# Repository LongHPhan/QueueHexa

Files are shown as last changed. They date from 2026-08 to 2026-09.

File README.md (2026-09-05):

# QueueHexa

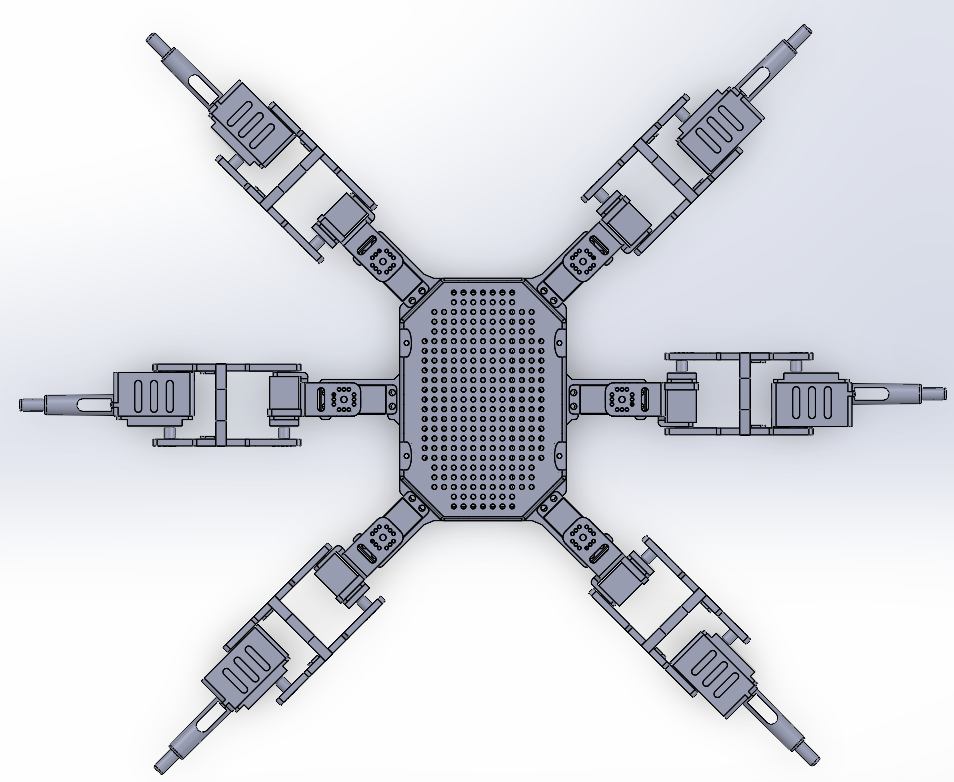
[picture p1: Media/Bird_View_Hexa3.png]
Hexapod Bird View


## Demo Video
  - [Hexapod Demo](https://youtu.be/oY_q5AbP_lc)

## Purpose
This is a personal robotics project created to hone my skills in CAD, electronics, and embedded programming. The idea is to design and build a six-legged hexapod robot from scratch: modeling, selecting the electronics, and programming custom inverse kinematics and gait control.

## Project Status
**In Development (Prototype Finished)**

Awaited improvements:
  - Add an accelerometer for motion/orientation feedback
  - Add leg position sensors
  - Integrate LiDAR for environmental sensing

## Hardware
  - Arduino Uno
  - PCA9685 servo driver(s)
  - MG996R servos
  - 35 kg high-torque servos
  - 7.4 V 5200 mAh battery
  - YPG 20A HV SBEC

## Development Journey
  Throughout the project, designing a reliable leg was one of the biggest challenges. The basic CAD process was simple; however, experimenting with the design in real life took multiple attempts before the leg was finally strong enough.
  
  For instance, the leg's joint went through two major changes: adding a peg and reinforcing the sides. These small details were overlooked in my initial design; however, their addition took the robot from crumbling under its own weight to being able to stand with only three of its legs.
  
  The hexapod's body also went through a similar process, however, with most changes aimed to minimize the usage of screws while considering space for electronics.
  
  The initial design was aimed to maximize modularity: the leg can be dissembled from the body plate was its own parts. However, the constant re-screwing made maintenance exhausting. With the 2nd prototypes, the layout changed from utilizing plates to a strong central frame, reducing the required screws to 4.

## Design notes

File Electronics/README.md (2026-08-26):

# Notice
One of the PCA address must be change to 0x41, to do so check out: https://learn.adafruit.com/16-channel-pwm-servo-driver/chaining-drivers.

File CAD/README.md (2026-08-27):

# Prototype
Both prototype 1 and 2 are fully functional with my current circuit and program. However, prototype 2 would provide a better experience as it is cleaner and uses significantly less screws. 

If you wished to use prototype 1, make sure your buck converter/UBEC/SBEC can provide a minimum of 15 amps.

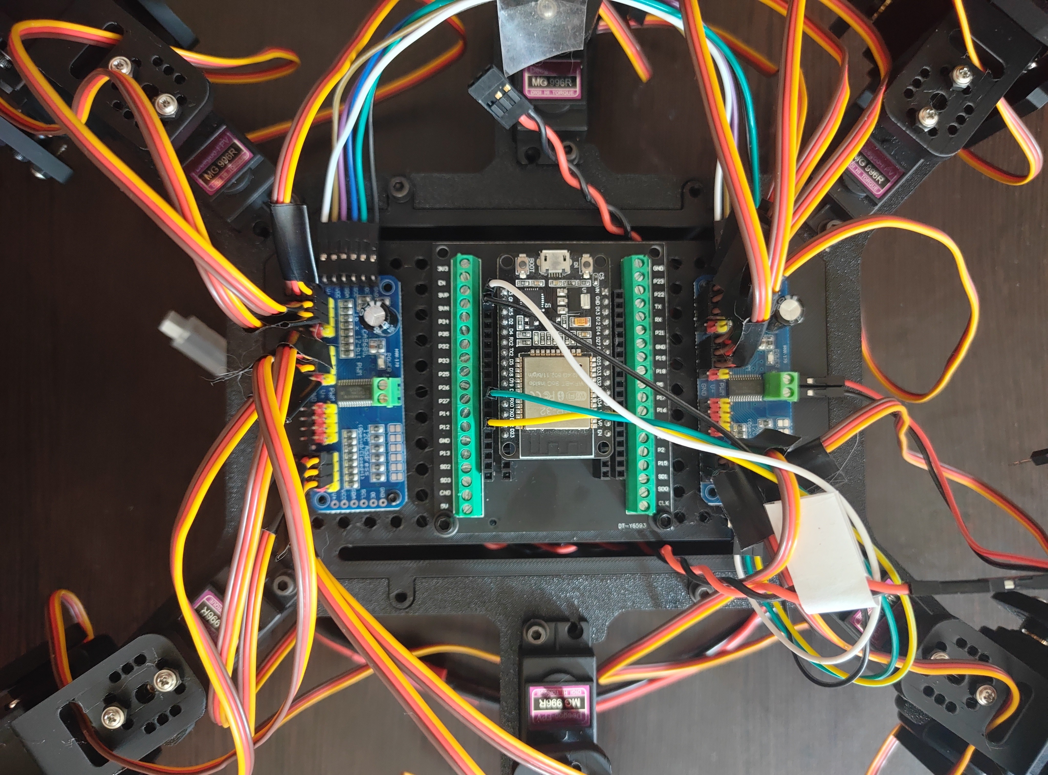
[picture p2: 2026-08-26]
Media/Protoype 2_Electronics.jpg

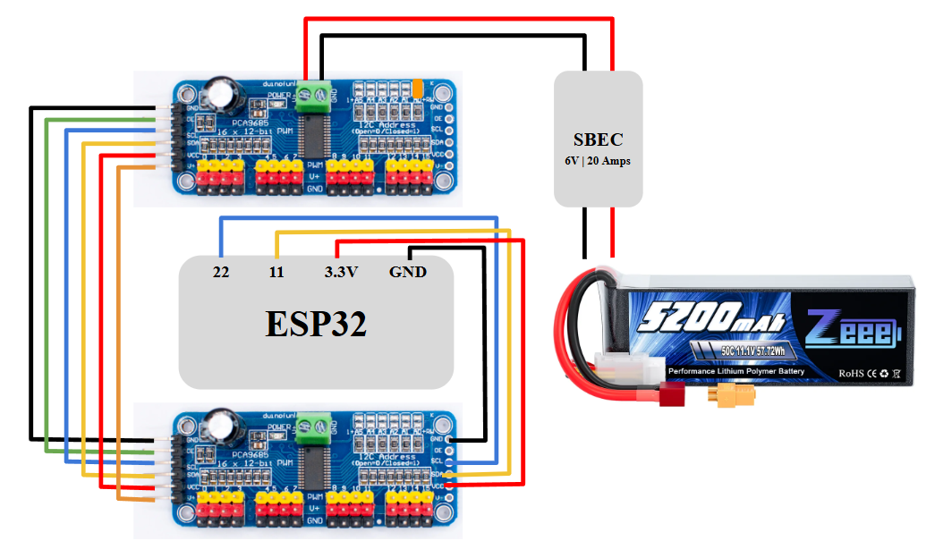
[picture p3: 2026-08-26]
Media/Circuit_Layout.png

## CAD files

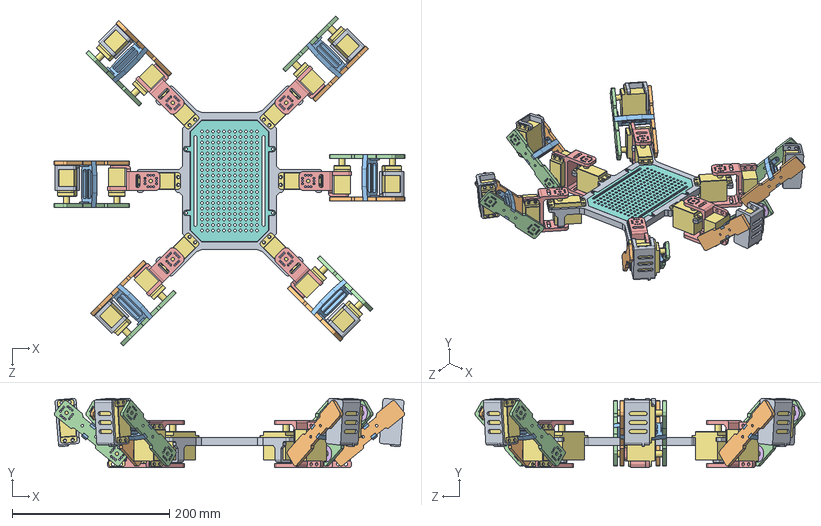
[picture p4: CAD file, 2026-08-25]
CAD/Prototype 2/Assembly/Hexa3_Assemble.SLDASM
445.7 x 87.9 x 419.7 mm
Frame_Hexa3
Plate_Hexa3
Servo x 18
Servo_Horn x 18
UJoint_Hexa3 x 6
Femur_Top_Bar_Hexa3 x 6
Femur_Ring_Hexa3 x 6
Femur_Bottom_Bar_Hexa3 x 6
Tibia_Hexa3 x 6

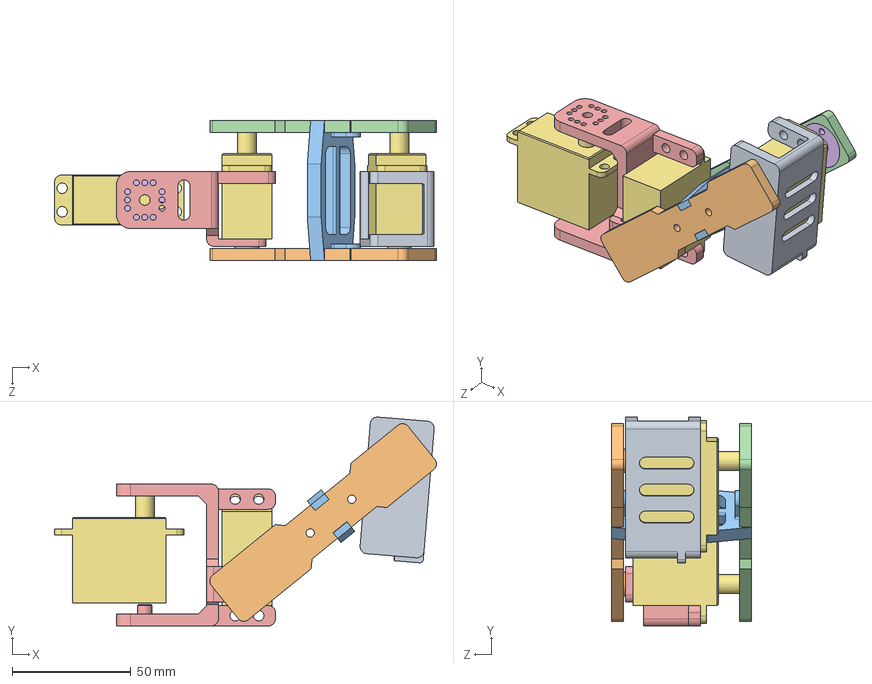
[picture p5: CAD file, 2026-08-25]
CAD/Prototype 2/Assembly/Leg_Assemble_Hexa3.SLDASM
160.8 x 87.9 x 59.0 mm
Servo x 3
Servo_Horn x 3
UJoint_Hexa3
Femur_Top_Bar_Hexa3
Femur_Ring_Hexa3
Femur_Bottom_Bar_Hexa3
Tibia_Hexa3

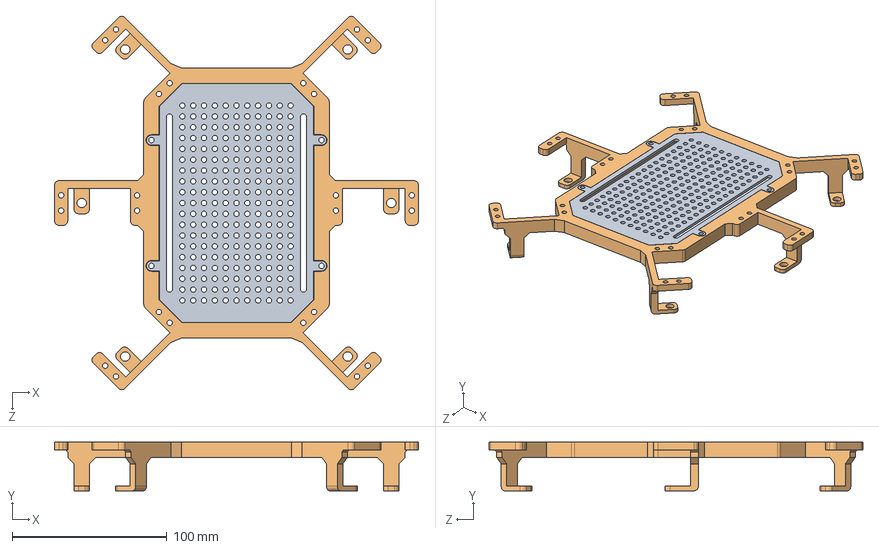
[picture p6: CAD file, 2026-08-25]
CAD/Prototype 2/Assembly/Base_Assembly_Hexa3.SLDASM
235.4 x 31.5 x 241.6 mm
Frame_Hexa3
Plate_Hexa3

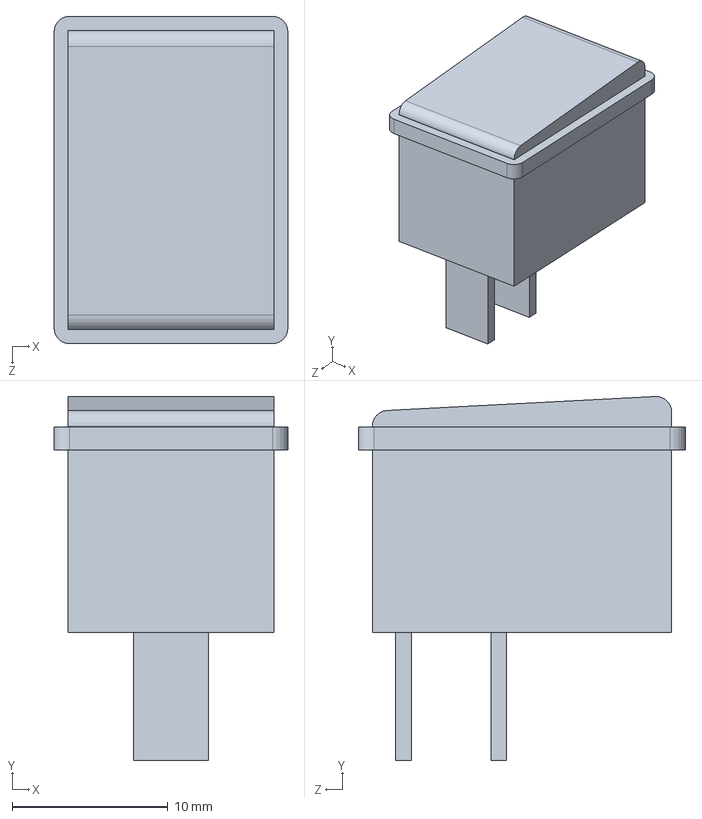
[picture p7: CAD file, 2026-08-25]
CAD/Electronics/KillSwitch.SLDPRT
15.0 x 23.3 x 21.0 mm

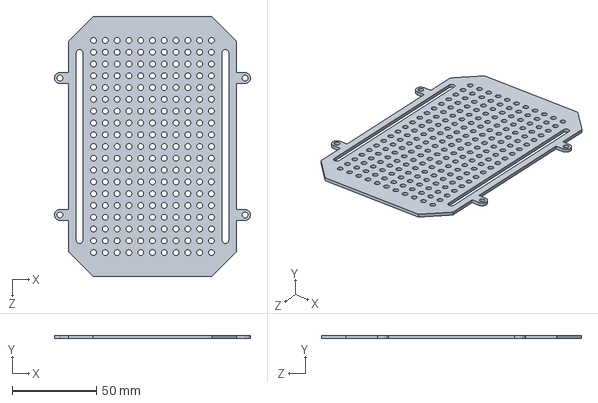
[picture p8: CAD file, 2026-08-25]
CAD/Prototype 2/Base/Plate_Hexa3.SLDPRT
116.5 x 2.00 x 154.4 mm

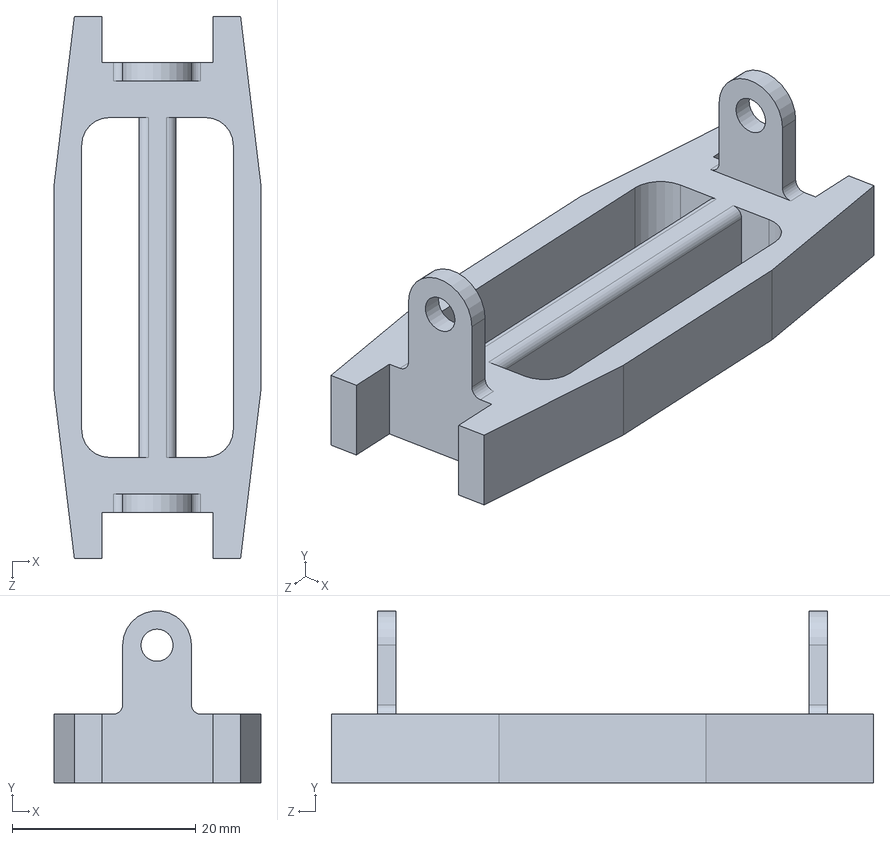
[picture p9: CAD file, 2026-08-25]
CAD/Prototype 2/Leg/Femur_Ring_Hexa3.SLDPRT
22.5 x 18.7 x 59.0 mm

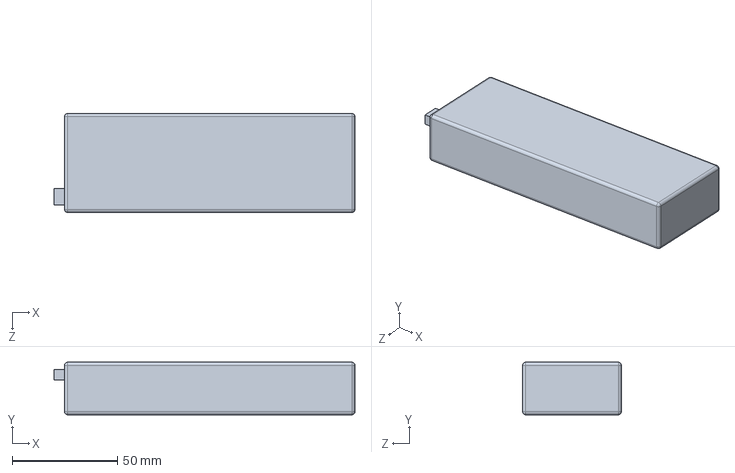
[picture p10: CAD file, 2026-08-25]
CAD/Electronics/LiPoBattery.SLDPRT
143.0 x 25.0 x 47.0 mm

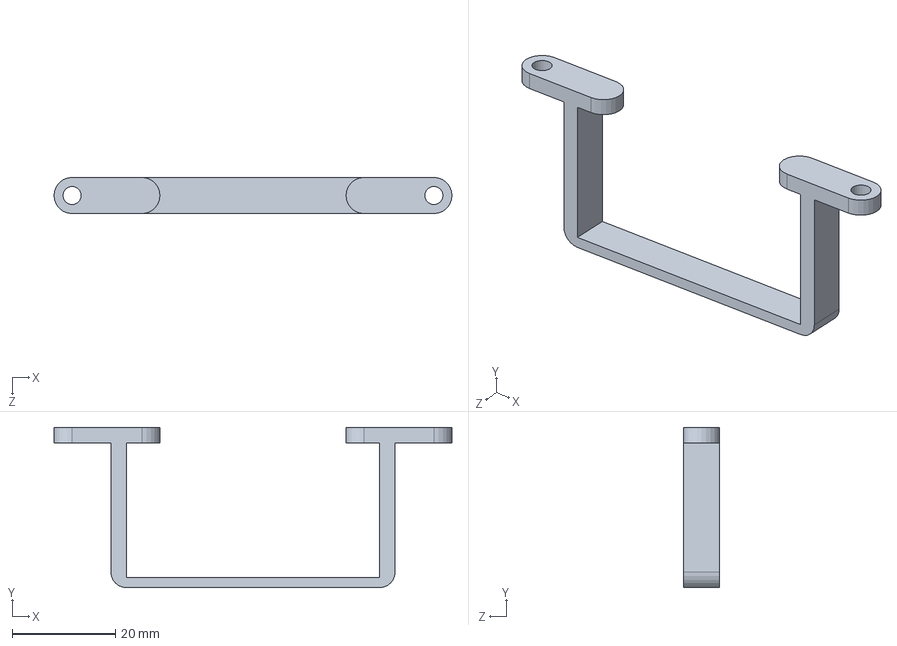
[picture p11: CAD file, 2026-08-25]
CAD/Prototype 2/Base/Battery_Holder_Hexa3.SLDPRT
77.0 x 31.0 x 7.00 mm

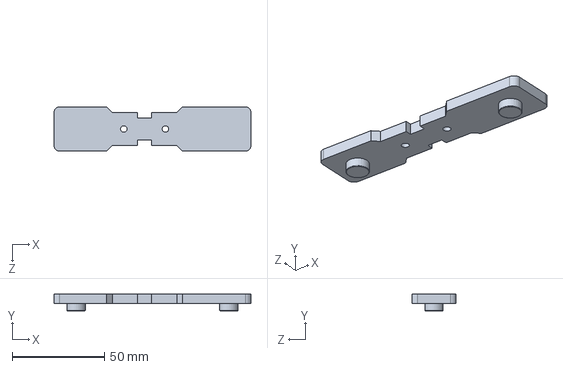
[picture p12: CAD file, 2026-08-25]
CAD/Prototype 2/Leg/Femur_Bottom_Bar_Hexa3.SLDPRT
106.5 x 9.00 x 24.0 mm

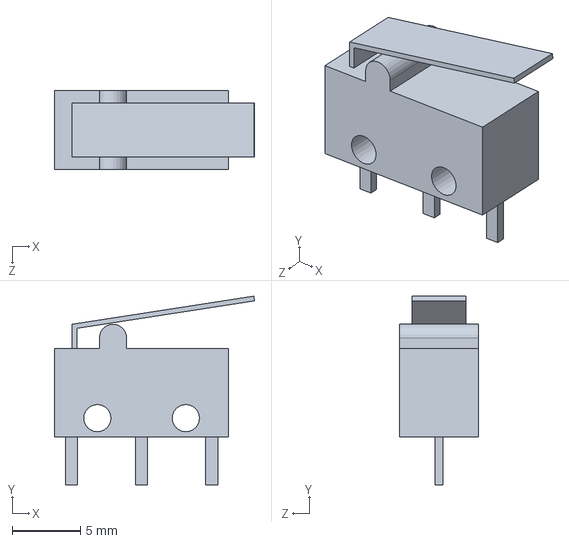
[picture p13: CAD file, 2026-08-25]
CAD/Electronics/Micro_Switch.SLDPRT
14.7 x 13.9 x 5.80 mm

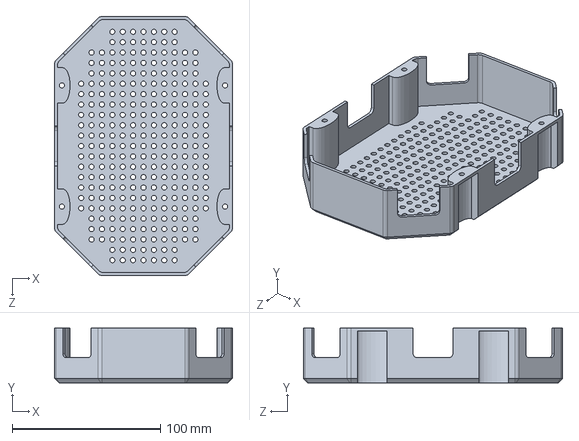
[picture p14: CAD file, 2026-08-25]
CAD/Prototype 2/Base/Top_Base_Hexa3.SLDPRT
120.0 x 37.0 x 174.6 mm

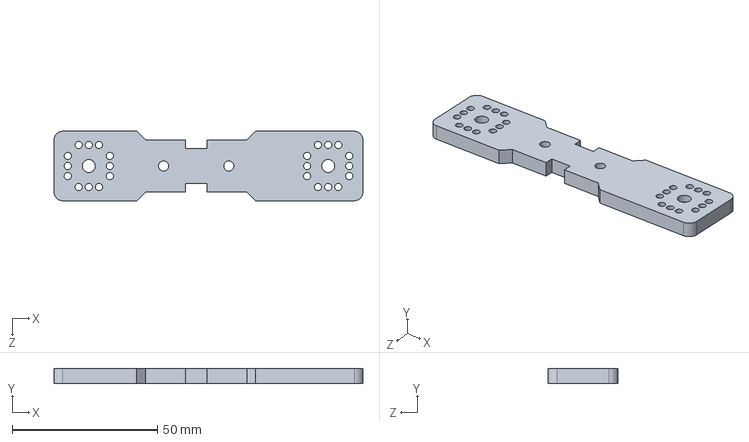
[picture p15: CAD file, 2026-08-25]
CAD/Prototype 2/Leg/Femur_Top_Bar_Hexa3.SLDPRT
106.5 x 5.00 x 24.0 mm

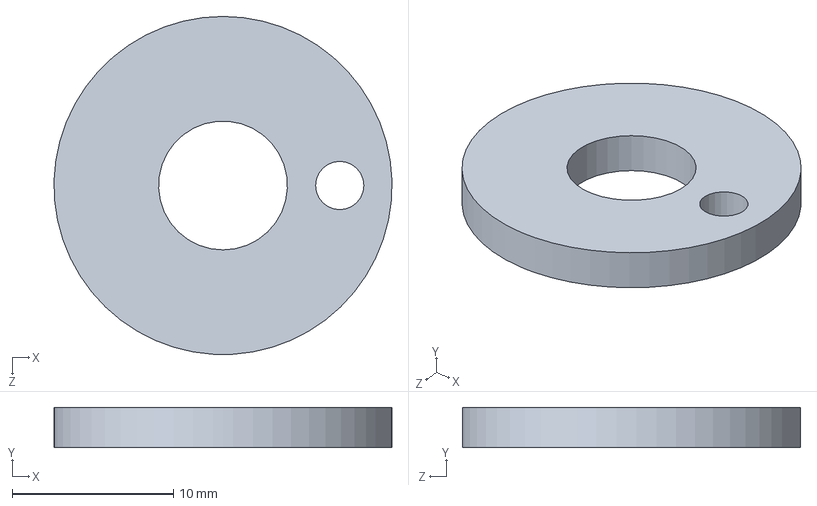
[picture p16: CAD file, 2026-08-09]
CAD/Electronics/Servo_Horn.SLDPRT
21.0 x 2.50 x 21.0 mm

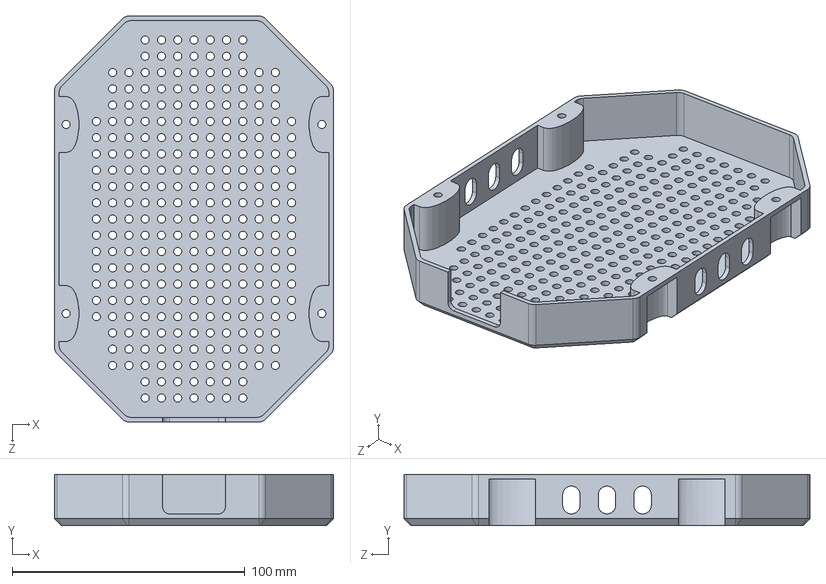
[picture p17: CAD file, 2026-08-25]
CAD/Prototype 2/Base/Bottom_Base_Hexa3.SLDPRT
120.0 x 22.0 x 174.6 mm

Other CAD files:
CAD/Prototype 2/Leg/Tibia_Hexa3.SLDPRT
CAD/Prototype 2/Base/Frame_Hexa3.SLDPRT
CAD/Prototype 2/Leg/UJoint_Hexa3.SLDPRT
CAD/Electronics/Servo.SLDPRT
CAD/Electronics/BreadBoard.SLDPRT
CAD/Electronics/PCA9685.SLDPRT
CAD/Electronics/Screw_Hexa2.SLDPRT
CAD/Electronics/UBEC.SLDPRT
CAD/Prototype 1/Assembly/Hexa3_Assemble.SLDASM
CAD/Prototype 1/Assembly/Leg_Assemble_Hexa3.SLDASM
CAD/Prototype 1/Base/3rd_Plate_Hexa2.SLDPRT
CAD/Prototype 1/Base/Base_Extender_Hexa2.SLDPRT
CAD/Prototype 1/Base/Bottom_Plate_Hexa2.SLDPRT
CAD/Prototype 1/Base/Box_Cover_Hexa2.SLDPRT
CAD/Prototype 1/Base/Box_Hexa2.SLDPRT
CAD/Prototype 1/Base/Top_Plate_Hexa2.SLDPRT
CAD/Prototype 1/Leg/Combined_UJoint_Hexa2.SLDPRT
CAD/Prototype 1/Leg/Femur_Joint_Hexa2.SLDPRT
CAD/Prototype 1/Leg/Leg_UJoint_Hexa2.SLDPRT
CAD/Prototype 1/Leg/Servo_Holder_Hexa2.SLDPRT
CAD/Prototype 1/Leg/Tibia_Hexa2.SLDPRT
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

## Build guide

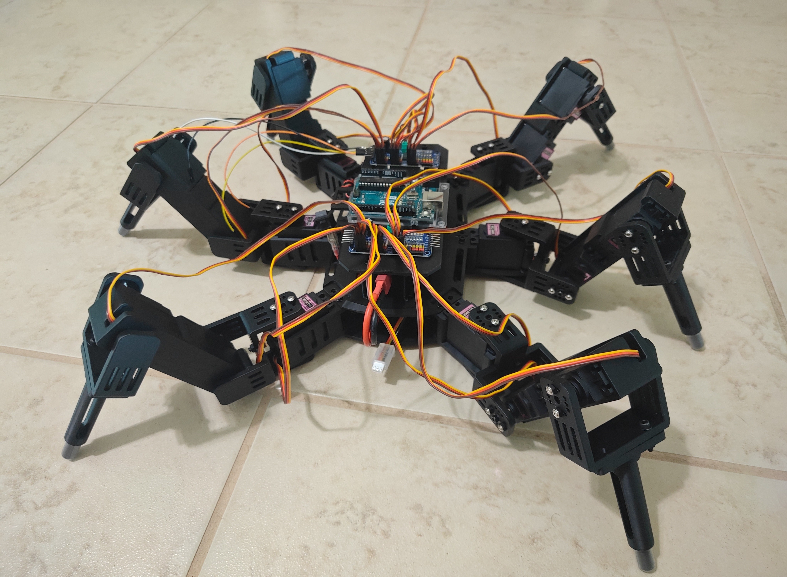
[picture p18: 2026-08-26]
Media/Assembled_Prototype 1_Front_View.jpg

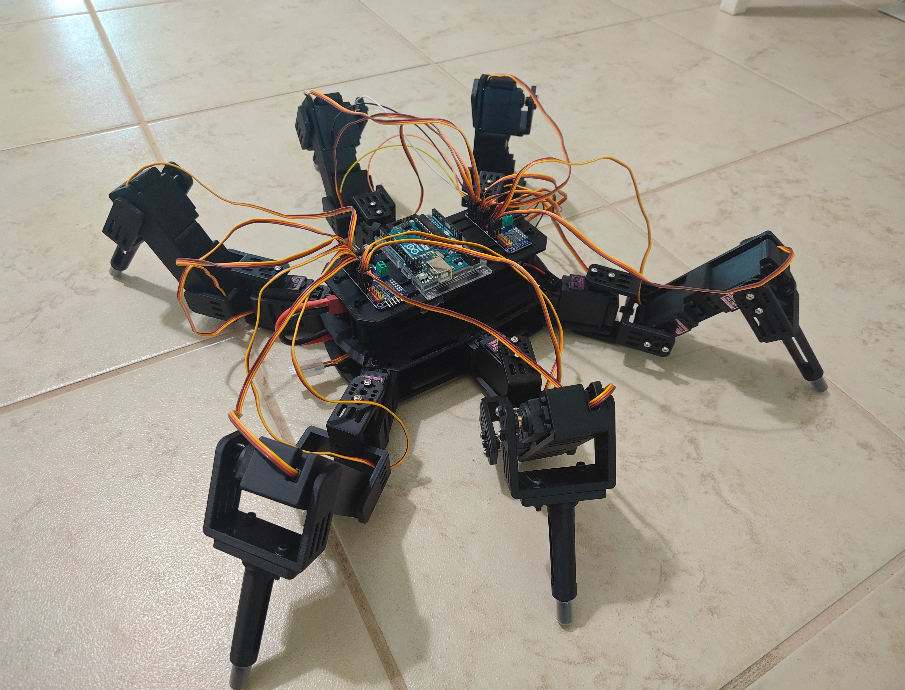
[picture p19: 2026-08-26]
Media/Assembled_Prototype 1_Side_View.jpg

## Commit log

2026-08-09 Create Legs
2026-08-25 Create .gitkeep
    Created CAD file
2026-08-25 Add files via upload
    Added electronics
    [BreadBoard.SLDPRT, KillSwitch.SLDPRT, LiPoBattery.SLDPRT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]
